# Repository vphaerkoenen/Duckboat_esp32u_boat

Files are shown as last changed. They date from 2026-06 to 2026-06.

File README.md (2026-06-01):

# Operation Duckboat

This is readme for operation duckboat, project that contains 3d-printed, remote controlled boat and controller. This document is for boat, you can find controller repo at https://github.com/vphaerkoenen/Duckboat_esp32u_remotecontrol.git. Both uses esp32u-boards and esp-now -protocol for communication. At the moment of writing this it is not proved how duckboat survives its itended use, being a ferry that pushes ducks from water when waterfowling. If you have great dog, maybe you should use that for hunting instead of duckboat. But duckboat can also be great project and lots of fun even without hunting if you like remote controlled things. 

I used 7.4v batteries and brushless 3650 kv4370 -motors which gives maybe total of one horsepower and it is fast enough for me. If you want to tune up, maybe you can use 11.1v batteries which can double the output. This requires mods in boat battery voltage measurement voltage divider and code, you have to drop voltage to safe level for esp32 analogread input. Also you should tune LM2596 -buck converter output voltage to 5 volt for esp32. In voltage divider i used 2*10K -resistors on top and one 10K at bottom which gives 2800 millivolts to esp32 input when charged to max of 8.4 volts, you should not exceed 3300mv. 

I think that my motor kv-rating is maybe bit too much, 4370*8.4 volts when charged gives max rpm of 36708 and i already blew plastic oem jet propeller. Because of this i printed heavy duty propeller which seems to withstand high rpm better, you can find this in stl-files. Propeller is made for 4mm shaft and outer diameter is 26mm. After printing propeller you should sand all imperfections for smooth surface, and also trim outer diameter that you have some clearance between propeller and housing to prevent contact at high rpm. If you have problems like motor loses thrust at high rpm, that propably means that you need smoother surface in propeller and sharp edge on front that cuts water cleanly. Uneven surface can cause "i-cant-understand" -problems at full thrust. 

I had problems with jets also because my balance was front-heavy. After printing rear nozzles and making balance rear-heavy problems were solved. If water outlet is on top of water level, even for a little while, air will flow to propeller inlet and thrust is gone. Problem can still occur when reverse, though. So balance your boat and install your parts so that outlets stays under water.

Tune your both esc to "bidirectional" to handle reverse. I used esc_config_tool 1.93 (https://am32.ca/downloads). 

I printed hull using PETG-filament but this can be made of large variety of materials. I printed whole hull at once using Anycubic Chiron but maybe it is safer if you split model in pieces in your slicer.

Parts list:
-	esp32u
-	6dbi external antenna with 15cm cord
-	LM2596 buck converter
-	6 * 10K resistors
-	2 * 3650 brushless motors, 4370kv
-	2 * 26mm water jet thrusters
-	2 * am32 esc
-	2 * 7.4 volt 6000mAh rc-batteries
- 	4 * xt90-connectors
-	2 * 100 amp manual circuit breakers (as main switches)
-	2 * 60 amp automatic reset circuit breakers
-	6mm^2 electric wire, 1.5mm^2 for smaller lines and small solid copper lines between esp/lm2596 pins.
    Check wiring at https://app.cirkitdesigner.com/project/83c7dbe5-4580-4fe7-96a1-f2cac5960db9
-	arduino plastic case for esp32/LM2596
-	low amperage blade fuse for esp32 feed
-	spring for cover push button (7mm diameter)
-	screws and zip ties
-	piece of copper plate for antenna mount (melted/pushed in place using soldering pen)
- 	small hose and plastic tubing for motor cooling
-	styrofoam (I filled whole lower part of boat, and also controller carrier when driving. This gives total of ~2.7 liters of volume which should float 2.7 kg. My boat weighs 3.7 kg, hopefully it does not leak much.)
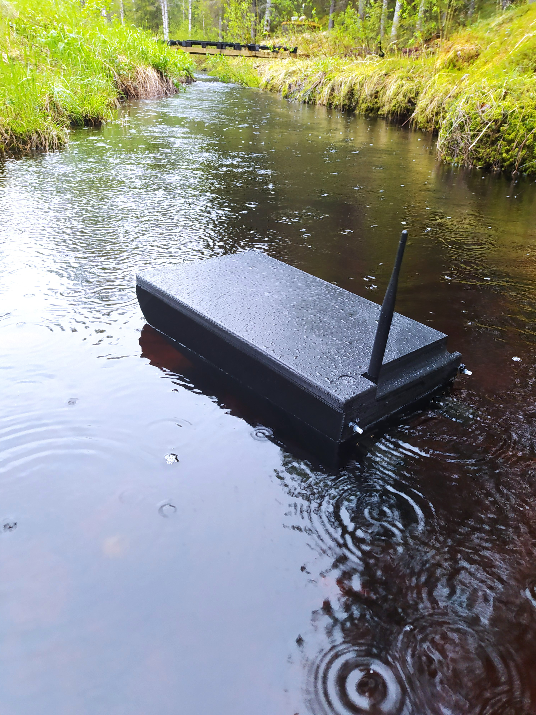
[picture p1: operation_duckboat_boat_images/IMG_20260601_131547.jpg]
Duckboat

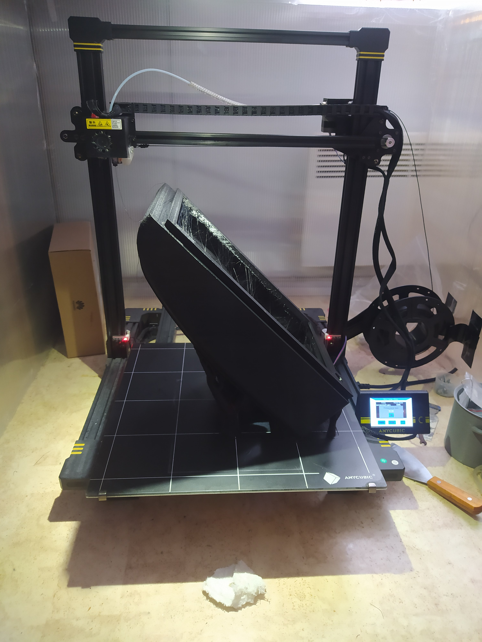
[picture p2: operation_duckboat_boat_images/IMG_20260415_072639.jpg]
Duckboat

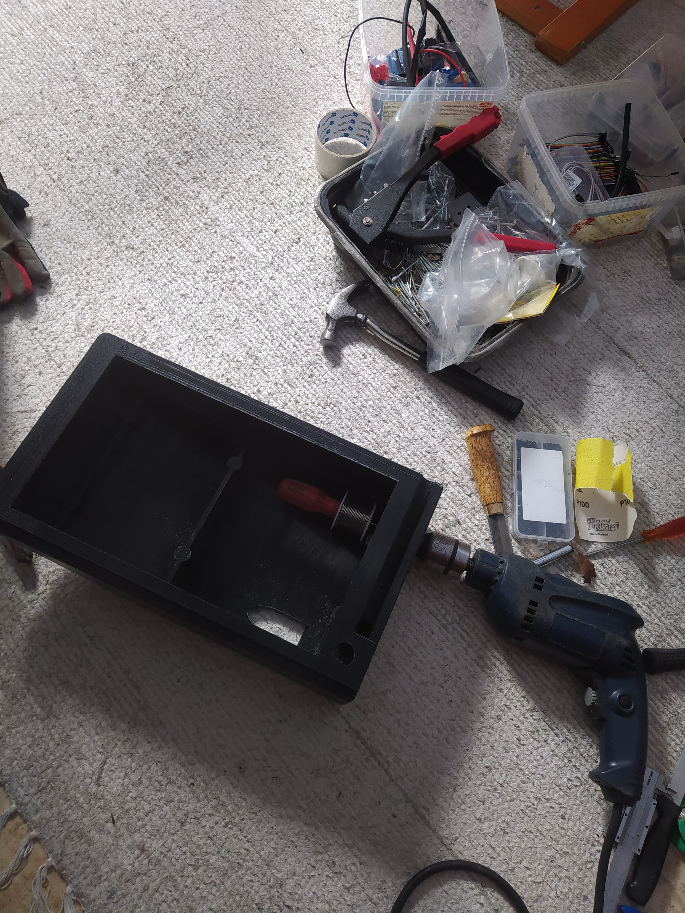
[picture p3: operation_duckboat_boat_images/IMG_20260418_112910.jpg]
Duckboat

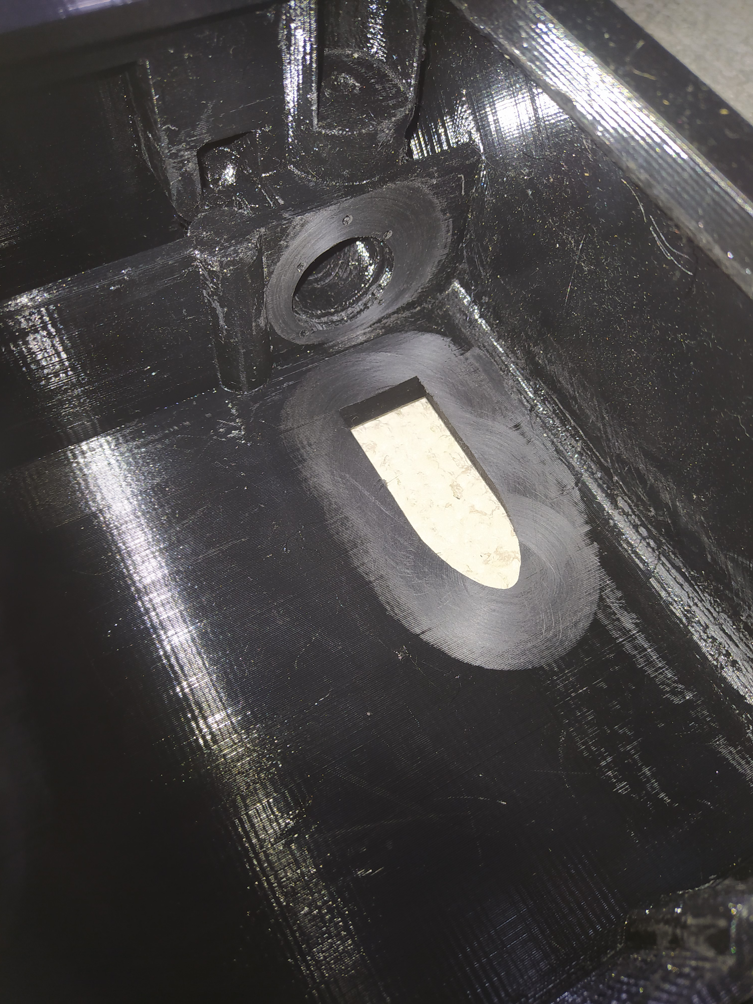
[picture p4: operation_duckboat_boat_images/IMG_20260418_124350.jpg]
Duckboat

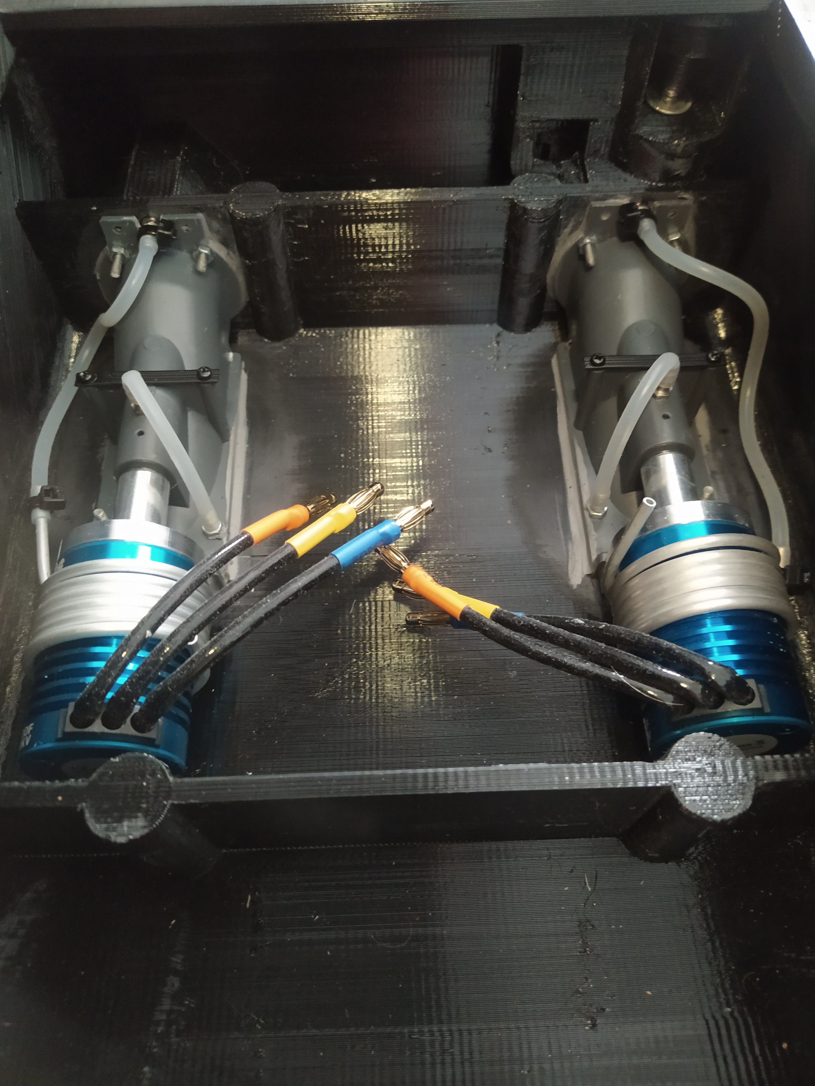
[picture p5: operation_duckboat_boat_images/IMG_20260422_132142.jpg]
Duckboat

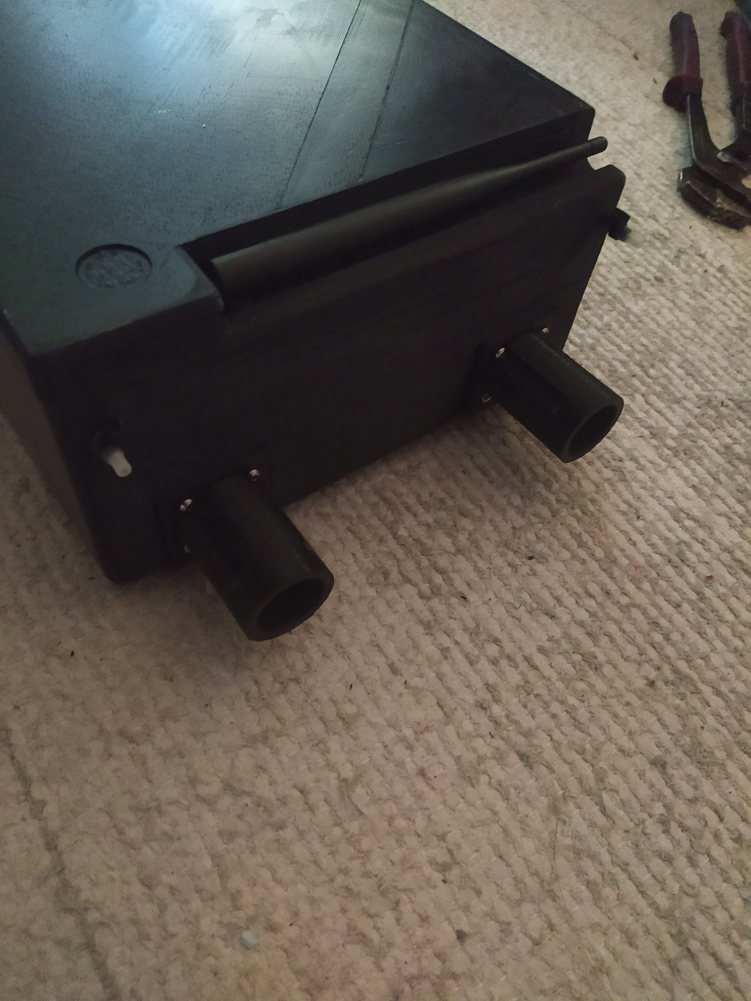
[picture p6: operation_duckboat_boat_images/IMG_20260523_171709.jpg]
Duckboat

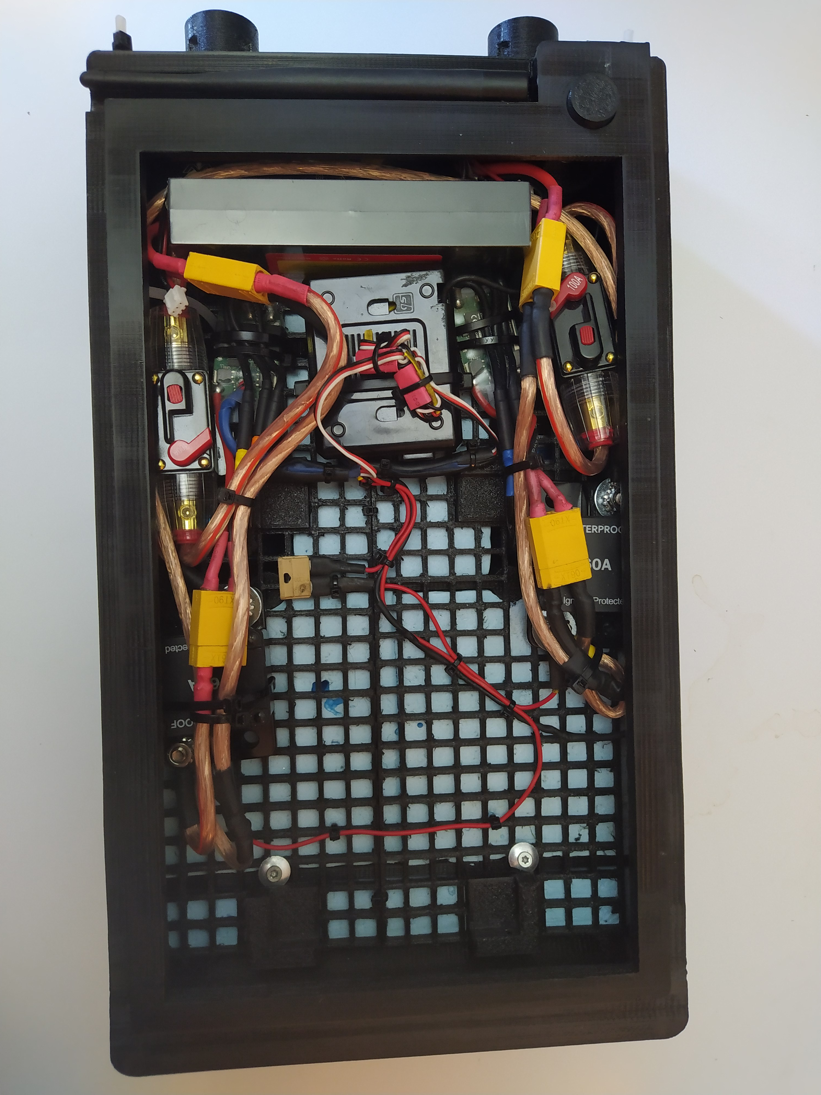
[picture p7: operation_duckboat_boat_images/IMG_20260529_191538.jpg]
Duckboat

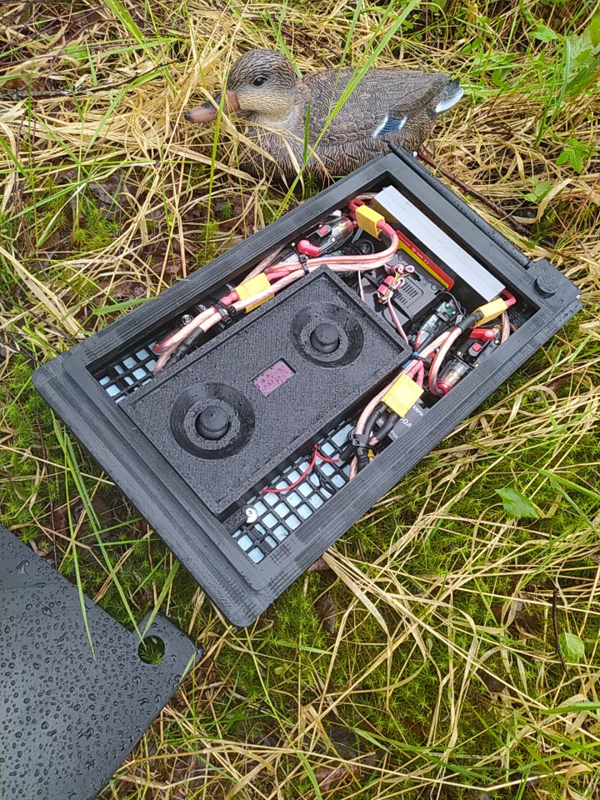
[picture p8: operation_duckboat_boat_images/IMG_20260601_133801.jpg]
Duckboat

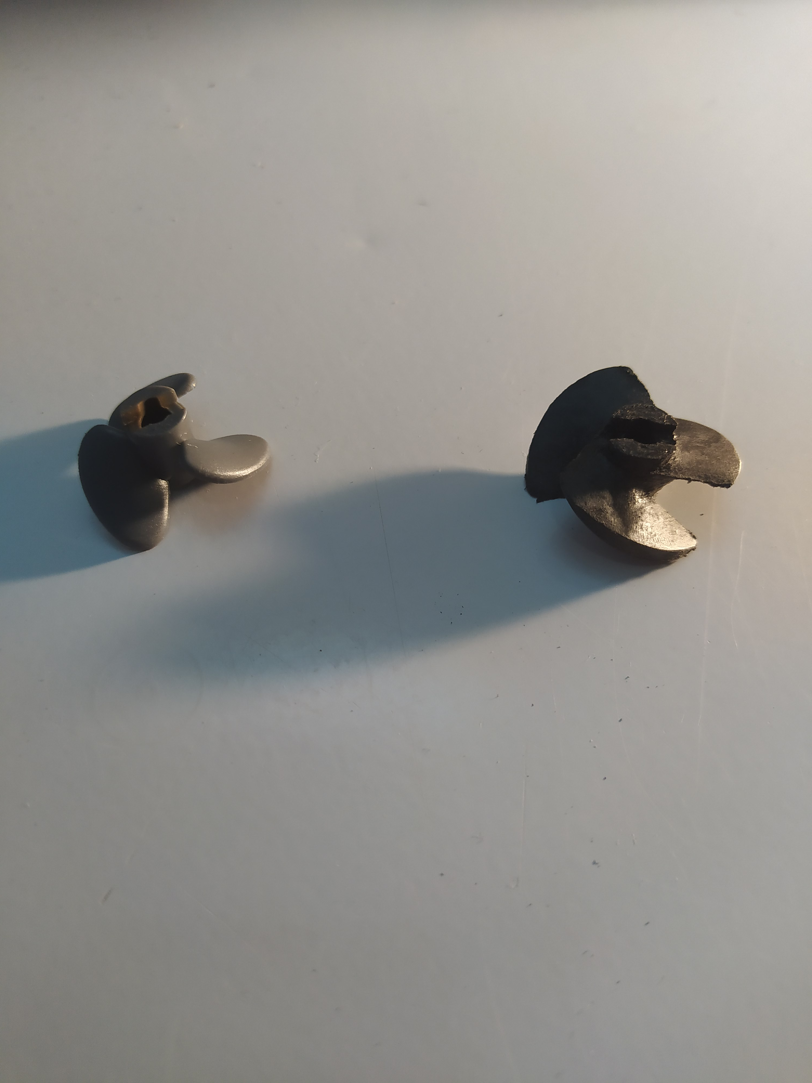
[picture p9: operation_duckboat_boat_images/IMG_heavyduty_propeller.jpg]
Duckboat

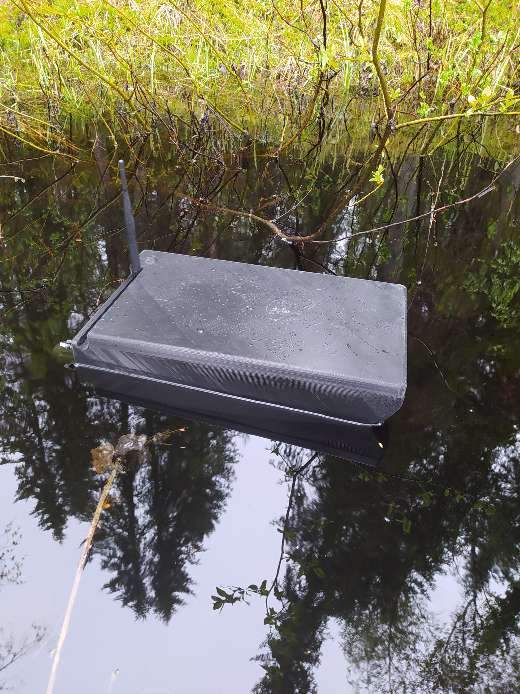
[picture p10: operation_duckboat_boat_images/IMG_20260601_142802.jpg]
Duckboat

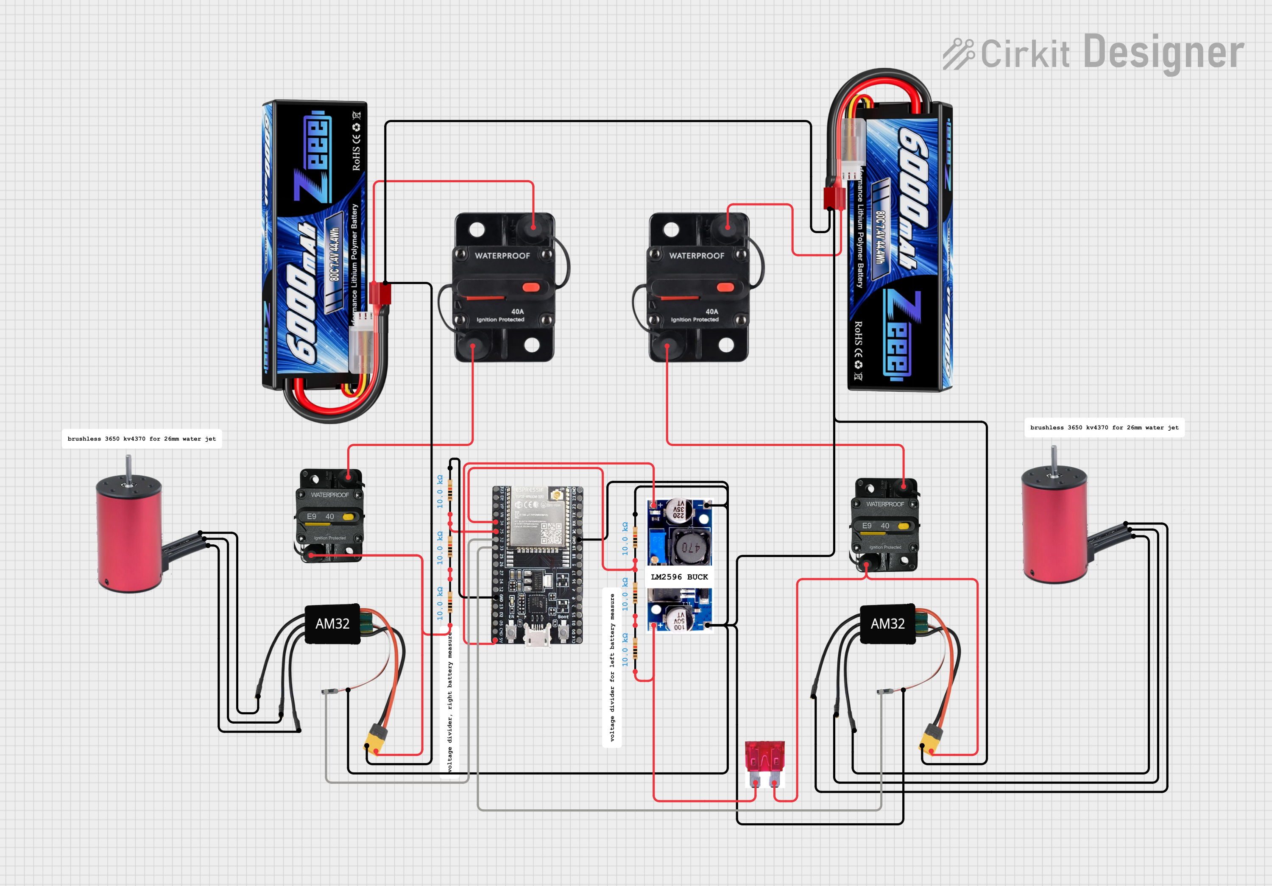
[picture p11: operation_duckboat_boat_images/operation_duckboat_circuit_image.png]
Duckboat


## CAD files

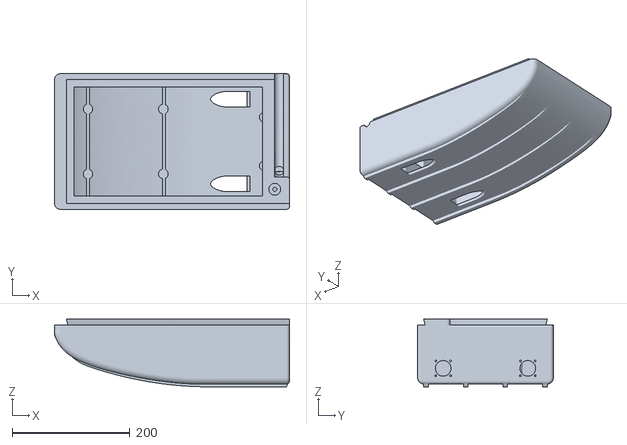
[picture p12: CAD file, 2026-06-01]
Duckboat_stl_files/duckboat_hull.stl
398.5 x 230.0 x 115.0

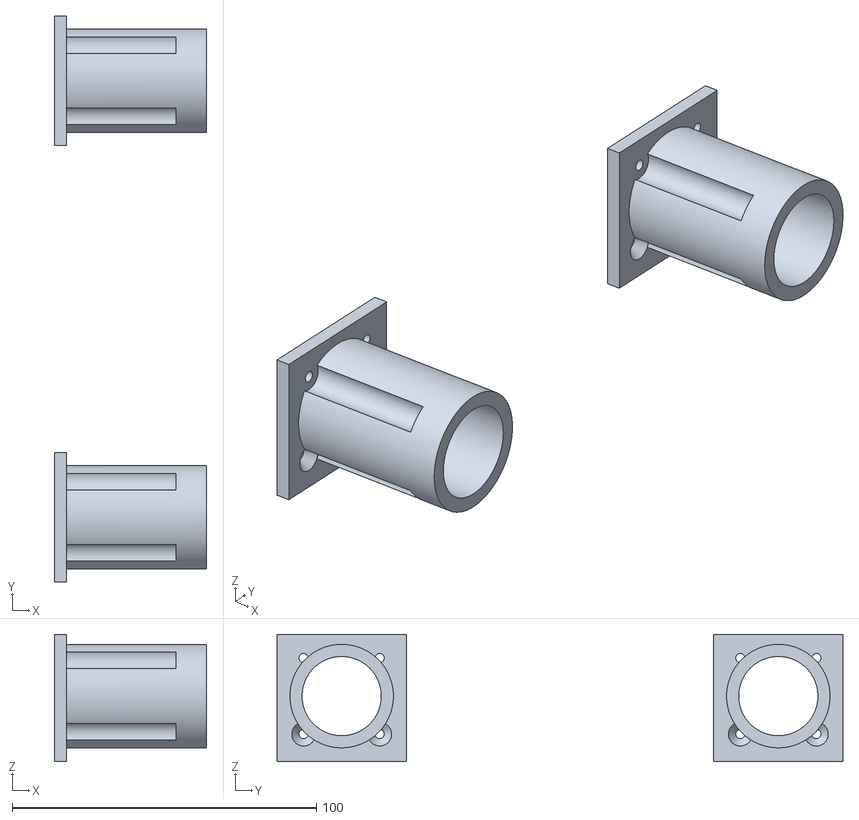
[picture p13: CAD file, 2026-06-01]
Duckboat_stl_files/duckboat_rear_nozzles.stl
50.0 x 186.0 x 41.8

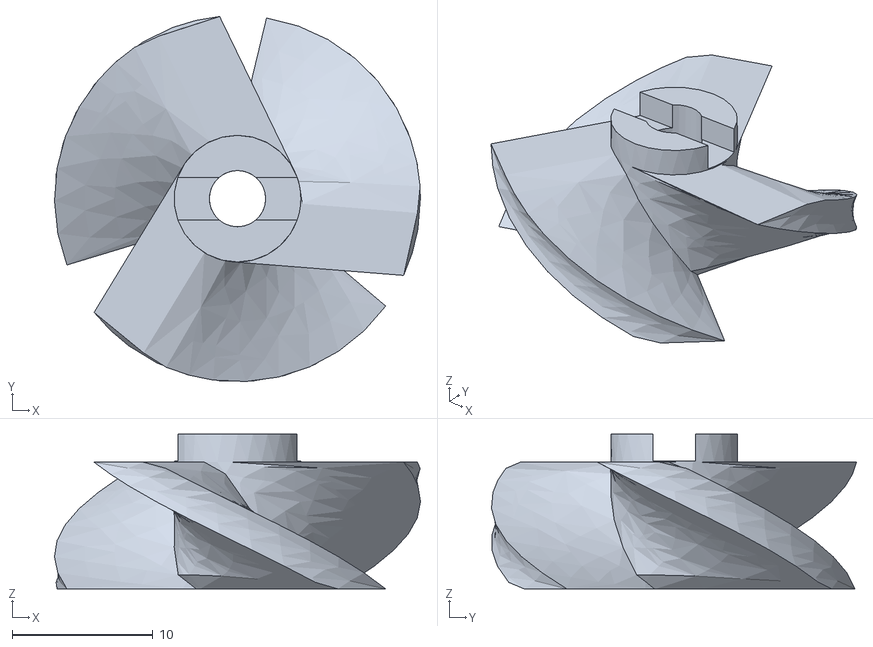
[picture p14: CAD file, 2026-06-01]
Duckboat_stl_files/duckboat_heavyduty_propeller.stl
26.0 x 25.9 x 11.0

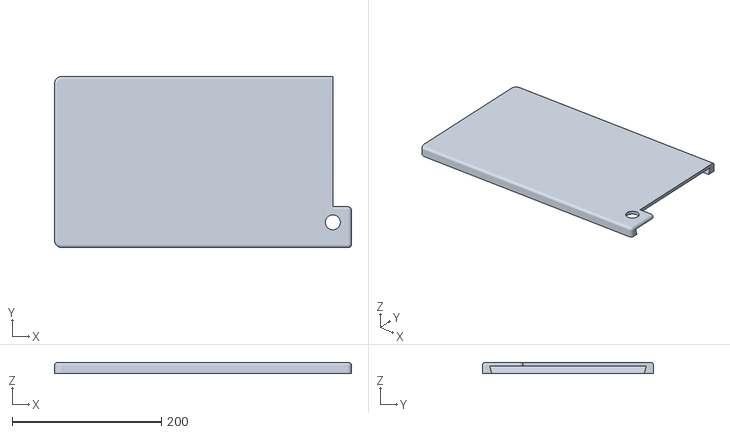
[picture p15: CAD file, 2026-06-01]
Duckboat_stl_files/duckboat_deck.stl
398.5 x 230.0 x 15.0

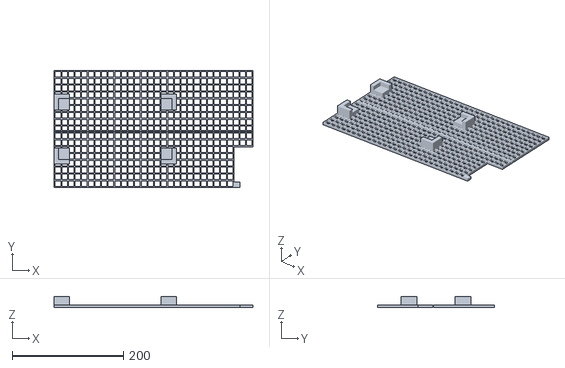
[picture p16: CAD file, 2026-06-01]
Duckboat_stl_files/duckboat_middle_floor.stl
357.0 x 210.0 x 20.0

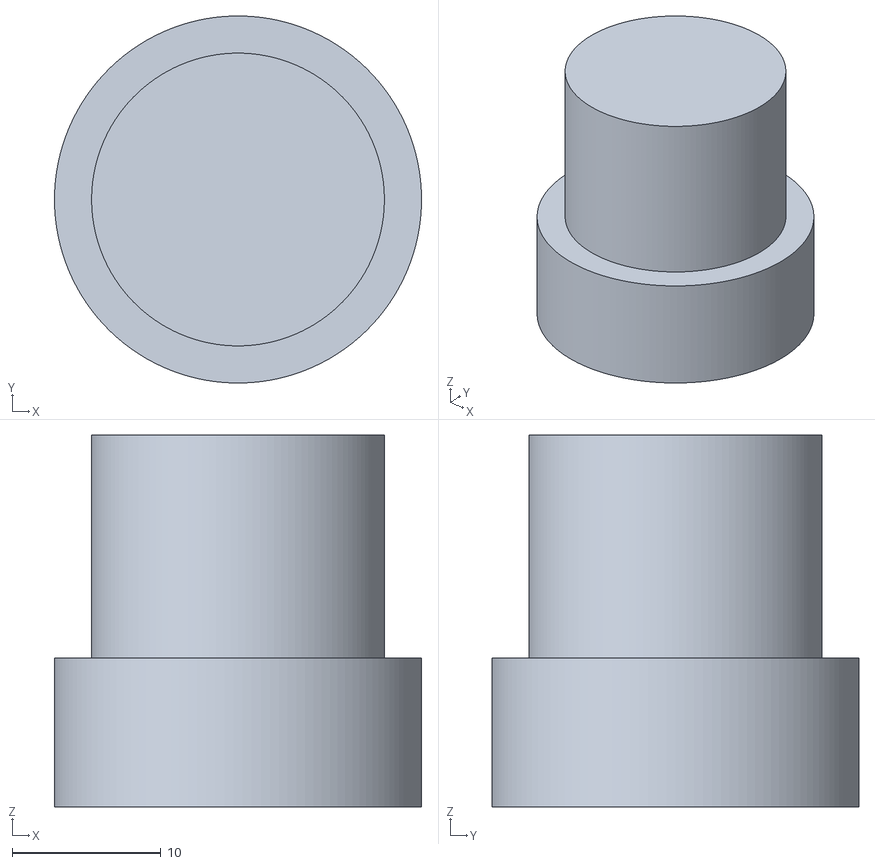
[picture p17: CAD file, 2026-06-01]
Duckboat_stl_files/duckboat_deck_pushbutton.stl
24.7 x 24.7 x 25.0

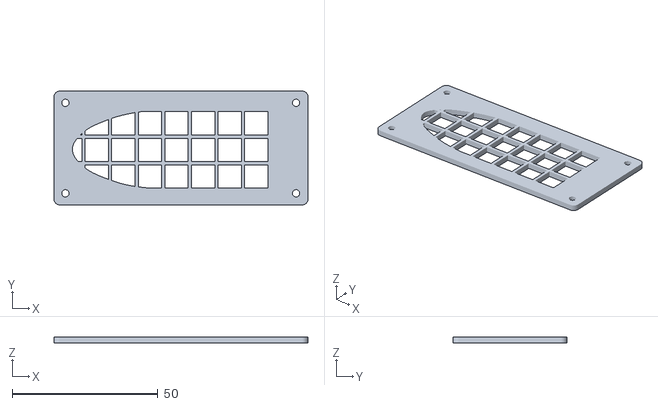
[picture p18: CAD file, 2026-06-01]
Duckboat_stl_files/duckboat_inlet_net.stl
87.0 x 39.0 x 2.00

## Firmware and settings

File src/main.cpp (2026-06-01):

//////////////////////////////////////////////////////////////////////////////////////////////////////////////////
//////////////////////////////////////////////////////////////////////////////////////////////////////////////////
////// OPERATION DUCK BOAT - BOAT CODE /////////////////////////////////////////////////////////////////////
//////////////////////////////////////////////////////////////////////////////////////////////////////////////////
//////////////////////////////////////////////////////////////////////////////////////////////////////////////////
/*
Author: Velipekka Härkönen 2026
*/
#include <Arduino.h>
#include "boat_espnow.h"
#include "measure.h"
#include "DataStructs.h"
#include "Addresses.h"
// #include "Addresses.example.h"   // use this for setting MAC addresses (remember to change the file name to Addresses.h after editing)
BoatEspnow boatEspnow;
Measure measure;
BoatDataStruct BoatData_Struct;
MotorControlStruct MotorControl_Struct;
ControlsUpdateStruct ControlsUpdate_Struct;

unsigned long clockStart;
unsigned long clockCurrent;
int measureInterval = 3000;        // interval for measuring battery voltage and sending data to controller in ms, default is 3 seconds
int controlInstructionsInterruptLimit = 100; // if no control signal in time limit -> emergency stop is activated

void setup()
{
  Serial.begin(115200);
  delay(1000);
  // espnow.findOwnAddress(); //   use this for finding own MAC-address (prints in serial monitor)
  boatEspnow.initializeWireless();
  boatEspnow.registerPeer(MAC_CONTROLLER);
  boatEspnow.initMotorControlPins();
  measure.initMeasurePin();
  clockStart = millis();
}

void loop()
{
  clockCurrent = millis();
  if (clockCurrent - clockStart > measureInterval) // time to measure battery voltage and send data to controller
  {
    BoatData_Struct.batteryStateBatteryLeft = measure.measureBoatBatteryLeftVoltage();
    BoatData_Struct.batteryStateBatteryRight = measure.measureBoatBatteryRightVoltage();
    boatEspnow.sendData(MAC_CONTROLLER, BoatData_Struct);
    clockStart = clockCurrent; // update clockStart for next measure
  }

  if (clockCurrent - ControlsUpdate_Struct.clock_ControlDataUpdated > controlInstructionsInterruptLimit) // if no control data received within the limit, activate emergency stop
  {
    if (!BoatData_Struct.booleanEmergencyStop) // stop the motors if emergency stop is not already active
    {
      boatEspnow.emergencyStop();
      BoatData_Struct.booleanEmergencyStop = true; // Update the boat data struct to indicate emergency stop
    }
  }
  else
  {
    BoatData_Struct.booleanEmergencyStop = false; // Reset emergency stop flag if control data is received within the limit
  }
}
